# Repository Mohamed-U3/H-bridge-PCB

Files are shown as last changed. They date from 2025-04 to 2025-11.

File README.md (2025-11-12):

# H-Bridge Motor Control PCB

A professional H-bridge motor driver PCB designed for bidirectional DC motor control with 24V power supply and microcontroller-based control interface.

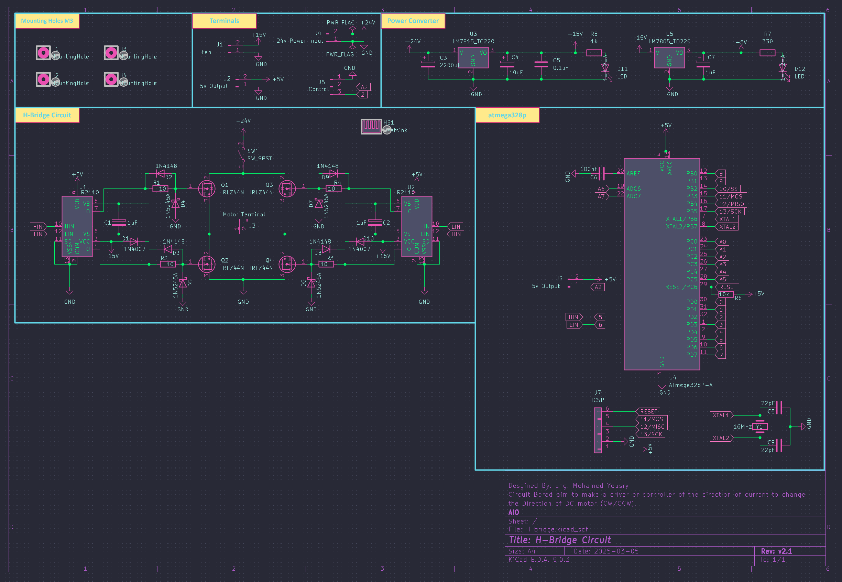
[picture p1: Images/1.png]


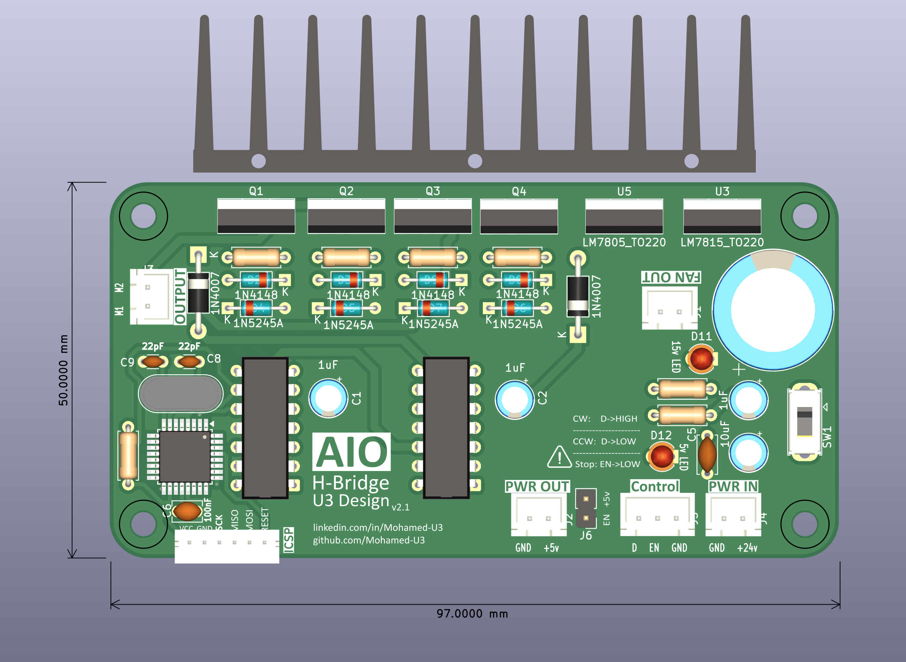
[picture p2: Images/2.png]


## Overview

This H-bridge circuit board enables bidirectional control of DC motors with overcurrent protection, isolated gate drivers, and integrated power regulation. The design features high-current MOSFETs capable of handling significant motor loads with proper heat dissipation.

**Designer:** Eng. Mohamed Yousry
**Company:** AIO
**Revision:** v2.1
**Date:** 2025-03-05

## Features

- **Power Supply:** 24V input with integrated voltage regulation

  - 24V → 15V regulation (LM7815) for gate drivers
  - 24V → 5V regulation (LM7805) for logic circuits
  - On-board 5V power distribution terminals
- **Motor Control:**

  - Full H-bridge configuration for bidirectional motor control
  - High-current IRLZ44N MOSFETs (47A Id, 55V Vds, 22mΩ Rds)
  - Motor terminal connector for easy connection
  - Power switch for main 24V supply
- **Gate Drivers:**

  - Dual IR2110 high/low side MOSFET drivers
  - Bootstrap capacitors for high-side gate driving
  - Isolated control signals (HIN/LIN)
- **Microcontroller Interface:**

  - ATmega328P-A microcontroller with arduino Framework (Arduino nano) (TQFP-32)
  - 16MHz crystal oscillator
  - ICSP programming header (6-pin)
  - Control interface connector (3-pin: GND, A2, 2)
- **Protection:**

  - Diode protection on all MOSFET gates (1N4148)
  - Zener diodes for voltage clamping (1N5245A)
  - Bootstrap diodes (1N5820 Schottky)
  - Freewheeling diodes (1N4007) for motor protection
- **Additional Features:**

  - Cooling fan connector (2-pin)
  - Heatsink mounting provision (125x35x50mm)
  - 4x M3 mounting holes for PCB installation
  - Status LEDs with current limiting resistors
  - Multiple power output terminals (5V, 15V)

## Technical Specifications

### Power Ratings

- **Input Voltage:** 24V DC
- **Regulated Outputs:**
  - 15V @ 1A (for gate drivers)
  - 5V @ 1A (for logic circuits)
- **Motor Current:** Up to 47A continuous (per MOSFET rating)
- **Switching Frequency:** Determined by microcontroller PWM (pin D5, D6)

### Key Components

- **MOSFETs:** 4× IRLZ44N (TO-220)
- **Gate Drivers:** 2× IR2110 (DIP-14)
- **Microcontroller:** ATmega328P-A (Arduino Nano) (TQFP-32)
- **Voltage Regulators:** LM7815, LM7805 (TO-220)
- **Crystal:** 16MHz (HC18-U)

## Schematic Sections

1. **Mounting Holes (M3):** Four 3.2mm mounting holes for secure PCB installation
2. **Terminals:** Power input, fan control, and auxiliary 5V outputs
3. **H-Bridge Circuit:** Four-quadrant MOSFET bridge with gate drivers
4. **Power Converter:** Voltage regulation from 24V to 15V and 5V
5. **ATmega328P:** Microcontroller with programming interface and I/O

## Pin Configuration

### Control Connector (J5)

| Pin | Function | Description |
| --- | --- | --- |
| 1 | GND | Ground reference |
| 2 | A2 | Analog control input for the speed |
| 3 | 2 | Digital control input for the Direction |

### ICSP Programming Header (J7)

| Pin | Function |
| --- | --- |
| 1 | RESET |
| 2 | 13/SCK |
| 3 | 11/MOSI  |
| 4 | 12/MISO  |
| 5 | GND |
| 6 | +5V |

### Motor Terminal (J3)

- 2-pin screw terminal for motor connection
- Motor polarity reversal controlled by H-bridge switching

## Operation

The H-bridge operates by controlling four MOSFETs in two half-bridge configurations:

- **Forward:** Q1 & Q4 ON, Q2 & Q3 OFF
- **Reverse:** Q2 & Q3 ON, Q1 & Q4 OFF
- **Brake:** All MOSFETs OFF or Q1 & Q3 ON (or Q2 & Q4 ON)

The IR2110 gate drivers provide isolated high and low-side gate drive signals with:

- **HIN (High-side Input):** Controls top MOSFETs (Q1, Q3)
- **LIN (Low-side Input):** Controls bottom MOSFETs (Q2, Q4)

The ATmega328P generates PWM signals for speed control and direction logic.

## Assembly Notes

- Use thermal paste when mounting MOSFETs to heatsink
- Ensure proper orientation of polarized components (electrolytic capacitors, diodes, LEDs)
- Bootstrap capacitors (C1, C2: 1μF) must be close to VB pins of IR2110
- Power supply bulk capacitor (C3: 2200μF) should be positioned near 24V input
- Verify all ground connections before applying power

## Heatsinking

The design includes provision for a 125x35x50mm heatsink with three M3 mounting points. All four MOSFETs should be thermally coupled to the heatsink using thermal compound and insulating pads if required.

## PCB Specifications

- **Board Size:** A4 (determined by KiCad export)
- **Layers:** 2-layer design
- **Mounting:** 4× M3 holes (3.2mm diameter)
- **Power Traces:** Heavy copper recommended for motor current paths

## Programming

The ATmega328P can be programmed via the ICSP header using an AVR programmer:

the code if included.

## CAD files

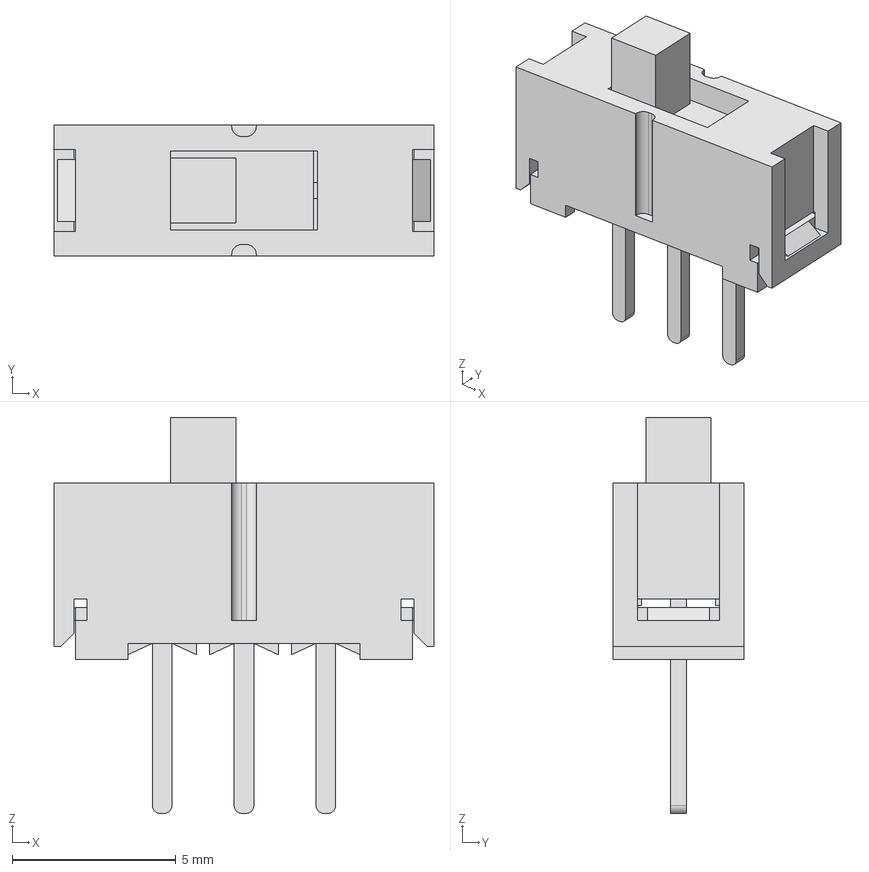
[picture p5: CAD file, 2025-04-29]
EG1218.step
11.6 x 4.00 x 12.1 mm

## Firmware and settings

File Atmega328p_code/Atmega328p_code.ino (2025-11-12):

#define EN    A2
#define DIR   2

#define HIN   5
#define LIN   6

void setup()
{
  pinMode(EN,   INPUT);
  pinMode(DIR,  INPUT_PULLUP);

  pinMode(HIN,  OUTPUT);
  pinMode(LIN,  OUTPUT);
}

void loop()
{
  static bool dirState = HIGH;

  if(digitalRead(DIR) == HIGH)                             //assume its CW direction
  {
    if(dirState == LOW)
    {
      digitalWrite(LIN, LOW);
      digitalWrite(HIN, LOW);
      delay(300);
    }
    int analogValue = analogRead(EN);                     // Read analog value (0-1023)
    int pwmValue = map(analogValue, 0, 1023, 0, 255);     // Map the analog value (0-1023) to PWM value (0-255)

    digitalWrite(LIN, LOW);
    if(pwmValue >= 254)     analogWrite(HIN, 254);
    else                    analogWrite(HIN, pwmValue);
    
    dirState    = HIGH; //changing the state variable.
  }
  else if(digitalRead(DIR) == LOW)                       //assume its CCW direction
  {
    
    if(dirState == HIGH)
    {
      digitalWrite(LIN, LOW);
      digitalWrite(HIN, LOW);
      delay(300);
    }

    int analogValue = analogRead(EN);                     // Read analog value (0-1023)
    int pwmValue = map(analogValue, 0, 1023, 0, 255);     // Map the analog value (0-1023) to PWM value (0-255)

    digitalWrite(HIN, LOW);
    if(pwmValue >= 254)     analogWrite(LIN, 254);
    else                    analogWrite(LIN, pwmValue);
    
    dirState    = LOW; //changing the state variable.
  }
  else
  {
    //there are only two state for these condition, so nothing to be done here.
  }
}

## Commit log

2025-04-29 First commit but it's version v2.0 already sorry.
    [EG1218.step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]
2025-04-29 this is v2.0 it has the IC IR2110. (not tested yet).
    [H bridge.kicad_pcb]
2025-04-30 the same thing just adding Atmega328p to give a PWM for the IR2110.
    [H bridge.kicad_pcb, H bridge.kicad_sch]
2025-05-05 version 2.1 with MCU Atmega328p that uses En and D pins for control only.
    [H bridge.kicad_pcb, H bridge.kicad_sch]
2025-05-05 small edit: adding 3d model for SW of the power SPDT
    [H bridge.kicad_pcb, H bridge.kicad_sch]
2025-05-07 just made some modification for the final revision.. I might manufacture this one.
    [H bridge-B_Cu.gbr, H bridge-B_Mask.gbr, H bridge-B_Paste.gbr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]
2025-06-18 small edit in pcb for fabrication.
    [H bridge-B_Cu.gbr, H bridge-B_Mask.gbr, H bridge-B_Paste.gbr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]
2025-07-01 Feat: New SW for the Power + small changes.
    [H bridge.kicad_pcb, H bridge.kicad_sch]
2025-07-01 fix: small modifications on the PCB for perfection =D.
    [H bridge.kicad_pcb, H bridge.kicad_sch]
2025-07-16 fix: small change in silkscreen cuz the EN and D was swaped :P
    [H bridge.kicad_pcb]
